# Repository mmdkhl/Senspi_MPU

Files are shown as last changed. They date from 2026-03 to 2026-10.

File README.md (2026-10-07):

# SensePi — ProTELC Science Camp

SensePi is a desktop app for measuring how a model structure vibrates. It connects over the network to a
Raspberry Pi that has **four MPU6050 motion sensors** attached. You can watch the signals live, record
them, look at their frequency content, and compare them with a computer model of the structure.

This page shows you how to get the app running on **your own computer** for the first time. It takes
about 15 minutes, and most of that is waiting for downloads.

> **At the camp, the Raspberry Pis are already set up for you.** All you need is the app on your laptop
> and the connection details (IP address, username, password) your instructor gives you. To talk to
> a Pi, your laptop must be connected to the **`MissionControl`** Wi-Fi network.

---

## Quick start

### Step 1: Install the tools (one time only)

You need two free programs:

| Program | Where to get it | Notes |
|---|---|---|
| **Python 3.12** | https://www.python.org/downloads/release/python-31210/ | On Windows, tick **"Add python.exe to PATH"** on the first installer screen. |
| **Git** | https://git-scm.com/downloads | The default options are fine. |

Use **Python 3.12**. Newer versions (3.13, 3.14) install without errors, but on Windows the *Model
Updating* tab then fails, because its OpenSees engine is only built for 3.12. If you already have a
different Python, install 3.12 next to it.

To check that both are installed, open a **new** terminal (Windows: press the Start key and type
`PowerShell`; macOS: open *Terminal*) and run:

```bash
python --version
git --version
```

The first command should print `Python 3.12.x`. On macOS/Linux, use `python3.12` in place of
`python`.

### Step 2: Download the app

The commands below download only the parts of the project the app needs, so the download stays small:

```bash
git clone --depth 1 --filter=blob:none --sparse https://github.com/mmdkhl/Senspi_MPU.git
cd Senspi_MPU
git sparse-checkout set src
```

This creates a folder called `Senspi_MPU` inside whatever folder your terminal was in (usually your
user folder). The rest of this guide runs commands **from inside that folder**.

<details>
<summary>No Git? Download a ZIP instead</summary>

Open https://github.com/mmdkhl/Senspi_MPU and click **Code → Download ZIP**. Unzip it, then open a
terminal in the unzipped folder. You get the whole project this way, which is fine but a bigger download.
</details>

### Step 3: Install the app

Create a private Python environment for the app so it doesn't interfere with anything else on your
computer, then install the app into it.

**Windows (PowerShell):**

```powershell
python -m venv .venv
.venv\Scripts\Activate.ps1
python -m pip install --upgrade pip
pip install -r requirements.txt
```

**macOS / Linux:**

```bash
python3 -m venv .venv
source .venv/bin/activate
python -m pip install --upgrade pip
pip install -r requirements.txt
```

`requirements.txt` installs **everything** — every tab works after this, including *Spectrum*,
*Model Updating* and the sound in *Sonification*. There is nothing else to add later.

When the environment is active, your prompt starts with `(.venv)`. The install downloads a few hundred MB
and can take several minutes.

> **Windows: "running scripts is disabled on this system"?** Run this once, then try
> `Activate.ps1` again:
> ```powershell
> Set-ExecutionPolicy -Scope CurrentUser RemoteSigned
> ```

### Step 4: Start the app

```bash
python main.py
```

The SensePi window opens. (On macOS/Linux use `python3` if `python` is not found.)

### Step 5: Connect to your Raspberry Pi

> **Connect your laptop to the `MissionControl` Wi-Fi network first.** The Raspberry Pis are only
> reachable on `MissionControl`, so the app can't find them from any other network. Do Steps 1–3 on a
> network with internet access, because `MissionControl` may not have any.

1. Open the **Settings** tab.
2. Under **Raspberry Pi hosts**, fill in the example entry like this:

   | Field | Value |
   |---|---|
   | **Name** | any name you like, for example `Pi-1` |
   | **Host / IP** | the Pi's IP address, from your instructor (the Pi's small screen also shows it) |
   | **User** | `verwalter` |
   | **SSH port** | `22` |
   | **Password** | from your instructor |
   | **Scripts base path** | `/home/verwalter/sensor4` |
   | **Data directory** | `/home/verwalter/logs` |
   | **Pi config path** | `/home/verwalter/sensor4/pi_config.yaml` |

   Type the paths exactly as shown. They point to the **4-sensor** scripts on the camp Pis.
3. Click **Save host config**.
4. Check that **Number of sensors** is set to **4 sensors**. This is the default.
5. In the **sensor map**, set the floor and position of each sensor to match your structure. Every other
   tab uses this map, so get it right here. Then click **Save sensors.yaml**.
6. Click **Sync Pi defaults (pi_config.yaml)** to send these settings to the Pi.

### Step 6: Measure!

1. Go to **Live Signals** and click **Start**. Tap the structure and watch the signals move.
2. Click **Stop** when you're done.
3. To keep a measurement, set the recording length and click **Smart Record**. The app checks the real
   sampling rate for a few seconds, then records for the length you chose.

---

## Starting the app again later

You only do Steps 1–3 once. After that, open a terminal and run:

**Windows:**
```powershell
cd Senspi_MPU
.venv\Scripts\Activate.ps1
python main.py
```

**macOS / Linux:**
```bash
cd Senspi_MPU
source .venv/bin/activate
python main.py
```

To get the latest version of the app (for example when your instructor announces an update), run this in
the `Senspi_MPU` folder:

```bash
git pull
```

---

## What's in the app

| Tab | What it does |
|---|---|
| **Live Signals** | Streams the four sensors live and records measurements |
| **Spectrum** | Shows which frequencies the structure vibrates at (its natural frequencies and mode shapes) |
| **Model Updating** | Tunes a computer (OpenSees) model of the structure so it matches your measurements. Its sub-tabs are Model, Additional Mass, Analysis, Calibration, **Digital Twin** (the tuned model's response beside the measurement) and **Digital Shadow** (the model run live alongside the real structure) |
| **Sonification** | Turns the vibrations into sound |
| **Settings** | Raspberry Pi connection, number of sensors, sensor positions and sampling rate |

### Where your data is saved

Everything the app produces goes into the `output/` folder inside `Senspi_MPU`:

```text
output/
  sensor_recordings/   your recorded measurements (one folder per recording)
  model/               computer-model files
  digital_twin/        Digital Shadow runs
  sonification/        audio you captured
```

---

## Troubleshooting

**`python` or `git` is "not recognized" / "command not found"**
Close the terminal and open a new one. If it still fails, reinstall Python and make sure **"Add
python.exe to PATH"** is ticked. On macOS/Linux, try `python3`.

**`No module named 'PySide6'` (or another package) when starting the app**
The environment isn't active. Run the `Activate` line from Step 3 — your prompt should show `(.venv)` —
then `python main.py` again. Run `python main.py` from inside the `Senspi_MPU` folder.

**The *Model Updating* tab says OpenSees is missing, or *Sonification* has no sound**
The dependencies didn't all install. With the environment active, run
`pip install -r requirements.txt` again and read the output for errors.

**Can't connect to the Pi**
- Is your laptop connected to the **`MissionControl`** Wi-Fi? (Laptops sometimes switch back to another
  saved network on their own.)
- Check the IP address, username and password in **Settings**.
- Ask your instructor whether the Pi is switched on. Its small screen shows its IP address.

**No signal / a sensor is missing**
- Check that **Number of sensors** is set to 4 and click **Sync Pi defaults (pi_config.yaml)** again.
- Check that the sensor cables are firmly connected, then tell your instructor.

**Plots are slow or jerky**
Lower the sample rate in **Settings**, or close other heavy programs.

---

## For instructors: preparing a Raspberry Pi

The Pi-side scripts for the 4-sensor setup (four MPU6050s on I2C buses 0 and 1, plus an OLED status
display) are in [`raspberrypi_scripts_4_sensor/`](raspberrypi_scripts_4_sensor/). Its
[`README_rpi.md`](raspberrypi_scripts_4_sensor/README_rpi.md) covers wiring, copying the scripts to the
Pi, installing dependencies (offline wheels included) and checking the sensors.

A student clone made with Step 2 doesn't include that folder. To get it, run
`git sparse-checkout add raspberrypi_scripts_4_sensor`, or clone the full repository.

Notes:
- The camp Pis use the user `verwalter`, with the 4-sensor scripts copied to `/home/verwalter/sensor4`.
  The student setup (Step 5) depends on these paths, so keep them the same on every Pi.
- `output_dir` in `pi_config.yaml` must be `/home/verwalter/logs/mpu` (inside the `verwalter` home
  directory).
- `deploy_pi.bat` / `deploy_pi.example.bat` copy the 4-sensor folder to the Pi. Set `REMOTE_DIR`
  (and the matching "Refusing to wipe" guard line) to the Pi's real folder first, for example
  `/home/verwalter/sensor4`: the script empties that folder before copying.

### Keeping credentials out of Git

The GUI saves real host details to `src/sensepi/config/hosts.local.yaml`, which Git ignores. The tracked
`hosts.yaml` / `hosts.example.yaml` contain placeholder values only. Never commit real IP addresses or
passwords.

---

## For developers

See [`docs/DEVELOPERS.md`](docs/DEVELOPERS.md) for the architecture, config files and tests.

`requirements.txt` is the complete dependency set and keeps step with `[project].dependencies` plus the
`model-updating` extra in `pyproject.toml`. OpenSees stays an extra in the package metadata (guardrail
G8) so `sensepi` can be imported as a library without it; `requirements.txt` installs it anyway, so the
app is always complete.

Installing the package itself adds the console commands:

```bash
pip install -e .          # adds sensepi-gui, sensepi-sonify, opensees-calibrate
sensepi-sonify --input path/to/data.csv --out out.wav --mode harmonic --joint 28 --r1-measurement R1 --u1-measurement U1
```

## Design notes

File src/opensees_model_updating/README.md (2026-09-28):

# opensees-model-updating

> Automated finite-element model updating for 3-D aluminum frames using OpenSeesPy and scipy.

A desktop application that builds a parametric OpenSees model of a multi-story 3-D moment frame, runs an automatic modal calibration against experimentally identified frequencies (and optionally mode shapes), then performs a Newmark transient analysis with real-time visualization — all driven by a three-tab Tkinter GUI.

---

## Table of contents

- [Background](#background)
- [How model updating works](#how-model-updating-works)
  - [The finite-element model](#the-finite-element-model)
  - [The calibration algorithm](#the-calibration-algorithm)
  - [The transient analysis](#the-transient-analysis)
- [Quick start](#quick-start)
- [Installation](#installation)
- [Running the application](#running-the-application)
- [GUI walkthrough](#gui-walkthrough)
- [Input files](#input-files)
- [Output files](#output-files)
- [Repository layout](#repository-layout)
- [Python API](#python-api)
- [Legacy reference](#legacy-reference)
- [Contributing](#contributing)

---

## Background

Structural model updating is the process of adjusting the parameters of a numerical finite-element model so that its dynamic behaviour matches measurements taken from a real structure. This repository implements a practical workflow for a scaled laboratory aluminum frame:

1. **System identification** — modal frequencies (and optionally mode shapes) are extracted from measured vibration data and stored in a JSON file.
2. **FE model construction** — OpenSeesPy builds a 3-D Euler–Bernoulli beam-column frame with rigid diaphragms, self-weight masses, and optional point masses.
3. **Automatic calibration** — a bounded nonlinear least-squares optimizer adjusts the Young's modulus scale and per-story mass scales to minimise the mismatch between numerical and experimental modal properties.
4. **Transient analysis** — the calibrated model is excited by a recorded ground-motion and the roof displacement response is animated in real time.

---

## How model updating works

### The finite-element model

The frame is a 1-bay-by-1-bay, N-story structure built entirely in OpenSeesPy:

- **Nodes** — four corner nodes and one master node per floor (plus four fixed base nodes). The master node sits at the geometric centroid of each floor.
- **Elements** — `elasticBeamColumn` elements for all columns and beams, using tabulated section properties derived from user-supplied dimensions (thickness × width for columns, height × width for beams).
- **Column orientation** — each column can be individually set to *weak-axis* or *strong-axis* bending relative to the X-direction of excitation. Internally this changes the geometric transformation vector from `(1,0,0)` to `(0,1,0)`.
- **Rigid diaphragm** — `ops.rigidDiaphragm(3, master, *corner_nodes)` constrains each floor to in-plane rigid-body motion in the horizontal plane.
- **Mass** — translational mass is lumped at the master node (self-weight) and optionally at each corner (additional point masses). The rotational mass moment of inertia for each floor is computed from its plan dimensions and total mass.
- **Gravity** — a static load case applies gravity to the corner masses, and `ops.loadConst('-time', 0.0)` resets the time origin before dynamic analysis.

Section properties are computed from standard thin-walled mechanics:

```
I = (b * h^3)/12  -  (b - 2t) * (h - 2t)^3 / 12
A = b*h  -  (b - 2t)*(h - 2t)
J ≈ 2*t*(b-t)^2*(h-t)^2 / (b + h - 2t)
```

### The calibration algorithm

The calibration is a **bounded nonlinear least-squares** problem solved by `scipy.optimize.least_squares` with the Trust-Region Reflective (`trf`) method and `soft_l1` loss (robust to outliers).

**Calibration parameters** — the optimizer searches over a vector:

```
x = [alpha_E,  alpha_m1,  alpha_m2,  ...,  alpha_mN]
```

where `alpha_E` scales Young's modulus and `alpha_mi` scales the mass of story `i`.
All scales start at `1.0` (no change) and are bounded to `[lb, ub]` (default 0.70–1.30).

**Objective function** — at each optimizer iteration the full OpenSees model is rebuilt and an eigenvalue analysis is run. The residual vector is:

```
r = [w_freq * (f_num_k - f_exp_k) / f_exp_k]   for k = 1 .. n_calib_modes
  + [w_mode * (phi_num_kj - phi_exp_kj)]        for each mode k, floor j  (optional)
```

where frequencies are in Hz and mode shapes are max-abs-normalised and sign-aligned before differencing. If the model fails during an optimizer iteration, a large penalty (1×10³) is returned to steer the solver away from that region.

**Eigenvalue solver fallback** — OpenSees uses ARPACK by default. For small models or when many modes are requested relative to the number of inertial DOFs, ARPACK can be numerically unstable. The code automatically retries with `fullGenLapack` if ARPACK fails.

**Result** — the optimizer returns the best-fit `x*` and the calibrated parameters become:

```
E_cal   = alpha_E*   * E_nominal
m_i_cal = alpha_mi*  * m_i_nominal    for each story i
```

### The transient analysis

After calibration, Rayleigh damping coefficients are computed from the first two numerical modes to target a uniform damping ratio `zeta`:

```
alpha = 2 * zeta * omega1 * omega2 / (omega1 + omega2)
beta  = 2 * zeta / (omega1 + omega2)
```

Ground motion is applied as a uniform base excitation in the X-direction via `ops.UniformExcitation`. The time integration uses the **Newmark average acceleration method** (`gamma = 0.5`, `beta = 0.25`, unconditionally stable). Floor displacement and acceleration recorders are written to `output/*.out`. During the run, a live matplotlib animation updates every 10 time steps, showing the deformed frame shape at 20× amplification alongside the roof displacement time-history. If a pre-calibration response was stored, it is overlaid in grey for direct visual comparison.

---

## Quick start

```bash
# 1. Clone the repository
git clone https://github.com/<your-org>/opensees-model-updating.git
cd opensees-model-updating

# 2. Create the conda environment
conda env create -f environment.yml
conda activate opensees

# 3. Run
python run.py
```

---

## Installation

### Requirements

| Dependency | Minimum version | Purpose |
|---|---|---|
| Python | 3.9 | Language runtime |
| openseespy | 3.4.0 | FE model + analysis |
| numpy | 1.20 | Numerical arrays |
| scipy | 1.7 | Least-squares optimizer |
| matplotlib | 3.3 | Plots + real-time animation |
| opsvis | 1.0 | Mode-shape visualisation |

### Step by step

```bash
# Using the provided environment file (recommended)
conda env create -f environment.yml
conda activate opensees

# Or manually
conda create -n opensees python=3.11
conda activate opensees
pip install openseespy numpy scipy matplotlib opsvis
```

---

## Running the application

```bash
# From the repository root, with the opensees environment active:
python run.py
```

---

## GUI walkthrough

The GUI has three tabs and two action buttons.

### Tab 1 — Basic Model

| Field | Description |
|---|---|
| Building length X / width Y | Plan dimensions in metres |
| Number of stories | Updating this field instantly rebuilds all story tables |
| Column thickness / width | Cross-section of each column (m) |
| Beam thickness / height | Cross-section of each beam (m) |
| Story height table | Per-story height (m) and self-weight floor mass (kg) |
| Columns present | Checkboxes C1–C4 per story; unchecked columns are omitted from the model |
| Column orientation | Per-story, per-column: Weak axis or Strong axis relative to X-shaking |

The 3-D sketch on the right updates live as you change the story count or column orientation.

### Tab 2 — Mass + Analysis

| Field | Description |
|---|---|
| Elastic modulus E | Young's modulus in Pa (e.g. `200e9`) |
| Poisson ratio ν | Used to derive shear modulus G |
| Additional mass table | Per-story extra masses (kg) at the floor centroid and corners C1–C4 |
| Number of modes | Total eigenvalues to extract from the FE model |
| Damping ratio ζ | Target Rayleigh damping ratio |
| Ground-motion file | Path to a plain-text acceleration record (m/s²) |
| Ground-motion dt | Sampling time step of the record (s) |
| Ground-motion scale factor | Multiplier applied to the record (e.g. `9.81` to convert g to m/s²) |
| Run transient after calibration | If unchecked, only modal analysis is performed |

### Tab 3 — Calibration

| Field | Description |
|---|---|
| Enable automatic calibration | Toggle the entire calibration step |
| Use mode shapes | Include mode-shape residuals in the objective (requires shapes in JSON) |
| Mass calibration target | Scale self-weight masses only, or self-weight + additional masses |
| Number of calibration modes | How many experimental modes to match (must be ≤ numModes and ≤ nStory) |
| Frequency / mode-shape weights | Relative weighting of the two residual components |
| E scale bounds | Lower and upper multiplier limits for Young's modulus |
| Mass scale bounds | Lower and upper multiplier limits for each story mass |
| Max optimizer evaluations | Hard cap on function evaluations; increase for tighter convergence |
| Show uncalibrated response | Overlay the pre-calibration roof response on the final animation |

### Action buttons

| Button | What it does |
|---|---|
| **Calibrate** | Runs calibration, saves all reports to `output/`, stores calibrated state in memory |
| **Run Analysis** | Uses the stored calibrated parameters (or current inputs if not yet calibrated) to run modal + transient analysis |
| Cancel | Exits the application |

> **Tip:** always click **Calibrate** before **Run Analysis**. If you change any input after calibrating, the application warns you and lets you choose whether to proceed uncalibrated or go back and recalibrate.

---

## Input files

### `input/experimental_modal_data.json`

The primary integration point. See [docs/pipeline.md](docs/pipeline.md) for the full data-flow reference and how to connect an automated sensor pipeline.

```json
{
  "frequencies_hz": [2.1, 5.8, 11.3],
  "mode_shapes_ux": [
    [0.33, 0.67, 1.00],
    [0.87, 0.50, -1.00],
    [1.00, -0.78, 0.34]
  ]
}
```

| Field | Required | Description |
|---|---|---|
| `frequencies_hz` | **Yes** | Identified natural frequencies in Hz, ordered lowest to highest |
| `mode_shapes_ux` | No | UX mode shape at each floor (bottom to top), one list per mode. Values need not be normalised. |

Rules:
- The list must contain at least `nCalibModes` entries.
- If `mode_shapes_ux` is provided, each inner list must have exactly `nStory` values.
- If omitted, calibration runs on frequencies only.

### `input/sine_*Hz_accel.txt`

Plain-text ground-motion records, one acceleration value per line (m/s²), sampled uniformly at `dtGM` seconds. Point the **Ground-motion file** field to whichever record you want to use.

---

## Output files

All files are written to `output/` relative to the working directory. The folder is gitignored (only `.gitkeep` is committed).

| File | Description |
|---|---|
| `original_inputs.json` | Full parameter dict before calibration |
| `calibrated_inputs.json` | Full parameter dict after calibration |
| `calibrated_inputs_used_for_run.json` | Exact parameters sent to transient analysis |
| `current_run_inputs.json` | Parameters for the most recent run |
| `experimental_modal_data_loaded.json` | Experimental data as parsed and validated |
| `modal_comparison_report.json` | Structured before/after comparison (frequencies, percent errors) |
| `modal_comparison_report.txt` | Human-readable version of the same report |
| `calibration_summary.png` | 4-panel figure: frequency bar chart, mass bar chart, mode shapes, text summary |
| `original_transient_response_overlay.npz` | Pre-calibration roof time-history for overlay plot |
| `original_periods.out` | OpenSees period file, original model |
| `calibrated_periods.out` | OpenSees period file, calibrated model |
| `*_mode_shapes_normalized.out` | Max-abs-normalised UX mode shapes |
| `*time_floor_disp_X.out` | Floor node displacement recorder |
| `*time_floor_accel_X.out` | Floor node acceleration recorder |
| `*time_roof_disp_X.out` | Roof master-node displacement recorder |
| `*time_roof_accel_X.out` | Roof master-node acceleration recorder |

---

## Repository layout

```
opensees-model-updating/
├── docs/
│   ├── pipeline.md                  # Data-flow reference + automation guide
│   ├── developer_guide.md           # Architecture, call graph, extension guide
│   └── legacy_monolith.py           # Original single-file script (reference only)
├── input/                           # Runtime input data (committed)
│   ├── experimental_modal_data.json
│   └── sine_*Hz_accel.txt
├── output/                          # Generated at run time (gitignored)
│   └── .gitkeep
├── src/                             # The Python package (opensees_model_updating)
│   ├── __init__.py
│   ├── __main__.py
│   ├── analysis/
│   │   ├── gravity.py           — static gravity + loadConst reset
│   │   ├── modal.py             — eigenvalue extraction, ARPACK fallback, plots
│   │   └── transient.py         — Rayleigh damping, Newmark integration, animation
│   ├── calibration/
│   │   └── calibrator.py        — TRF optimizer, residual function, bounds
│   ├── cli/
│   │   └── main.py              — post-GUI analysis orchestration
│   ├── domain/
│   │   └── enums.py             — ColumnOrientation, AnalysisType, MassCalibrationScope
│   ├── gui/
│   │   ├── main_window.py       — 3-tab Tkinter GUI, Calibrate + Run buttons
│   │   └── widgets/
│   │       └── canvas_widget.py — plan-view legend, 3-D column sketch
│   ├── io/
│   │   └── loaders.py           — JSON/text I/O, experimental data validation
│   ├── model/
│   │   └── builder.py           — nodes, elements, rigid diaphragm, mass
│   ├── reporting/
│   │   └── calibration_report.py — report dicts, text formatting, summary figure
│   ├── utils/
│   │   ├── formatters.py        — r3(), sci3(), deep_round(), layout text helpers
│   │   └── math_utils.py        — mode normalisation, sign alignment, percent error
│   └── visualization/
│       └── __init__.py          — re-exports from analysis modules
├── .gitattributes
├── .gitignore
├── environment.yml
├── pyproject.toml
├── README.md
└── run.py                           — one-line launcher
```

---

## Python API

The package can be used without the GUI for automated pipelines:

```python
import json
import pathlib
from opensees_model_updating.calibration.calibrator import (
    prepare_experimental_modal_data,
    run_calibration,
)
from opensees_model_updating.analysis.modal import extract_modal_results, export_modal_files
from opensees_model_updating.reporting.calibration_report import (
    make_modal_comparison_report,
    save_calibration_summary_figure,
)

# Write experimental data (replace with your sensor pipeline output)
pathlib.Path("input/experimental_modal_data.json").write_text(
    json.dumps({
        "frequencies_hz": [2.1, 5.8],
        "mode_shapes_ux": [[0.5, 1.0], [1.0, -0.6]],
    })
)

# Define model parameters (same keys that the GUI collects)
params = {
    "nStory": 2,
    "Lx": 0.245, "Ly": 0.23,
    "story_heights": [0.24, 0.24],
    "floor_masses": [0.27, 0.27],
    "t_column": 0.001, "b_column": 0.006,
    "b_beam": 0.001,   "h_beam": 0.008,
    "E": 200e9, "nu": 0.33,
    "numModes": 2, "nCalibModes": 2,
    "zeta": 0.005, "gmFactor": 9.81,
    "gmFile": "input/sine_1Hz_accel.txt", "dtGM": 0.01,
    "enable_calibration": True, "use_mode_shapes": False,
    "mass_calibration_scope": "self_weight_only",
    "freq_tol_percent": 5.0, "w_freq": 1.0, "w_mode": 0.35,
    "E_scale_lb": 0.70, "E_scale_ub": 1.30,
    "m_scale_lb": 0.70, "m_scale_ub": 1.30,
    "max_nfev": 200, "show_info": False,
    "story_column_layout": {1: [1,2,3,4], 2: [1,2,3,4]},
    "column_orientation_layout": {
        1: {1: "weak", 2: "weak", 3: "weak", 4: "weak"},
        2: {1: "weak", 2: "weak", 3: "weak", 4: "weak"},
    },
    "additional_masses": {1: [0,0,0,0,0], 2: [0,0,0,0,0]},
}

exp_data     = prepare_experimental_modal_data(params)
modal_before = extract_modal_results(params)
calib_result, calibrated_params = run_calibration(params, exp_data)
modal_after  = extract_modal_results(calibrated_params)

export_modal_files(modal_before, "original")
export_modal_files(modal_after,  "calibrated")

report = make_modal_comparison_report(
    exp_data, modal_before, modal_after, params, calibrated_params, calib_result
)
save_calibration_summary_figure(
    exp_data, modal_before, modal_after, params, calibrated_params,
    save_path="output/calibration_summary.png",
)
print("Calibrated frequencies (Hz):", modal_after["freqs"])
```

See [docs/pipeline.md](docs/pipeline.md) for the complete integration reference including how to feed live sensor data.

---

## Legacy reference

[docs/legacy_monolith.py](docs/legacy_monolith.py) is the original single-file script (`DigitalTwin_V8.py`) from which this package was refactored. It is kept for historical reference only — do not run or import it. The developer guide contains a [function-by-function mapping](docs/developer_guide.md#legacy-reference) from the old script to the current package modules.

---

## Contributing

1. Fork the repository and create a feature branch.
2. Follow the existing code style — `black` for formatting, `ruff` for linting.
3. Add or update tests under `src/tests/`.
4. Open a pull request with a clear description of the change.

```bash
# Format and lint before committing
black src/
ruff check src/
pytest src/tests/
```

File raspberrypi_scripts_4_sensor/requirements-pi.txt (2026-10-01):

# Python packages the 4-sensor Pi scripts import (installed by install_pi_deps.sh).
#   smbus2  - I2C access to the MPU6050s (mpu6050_multi_logger.py)
#   PyYAML  - reads pi_config.yaml (pi_logger_common.py, sensepi.config)
# The OLED display's packages are in requirements-oled.txt.
smbus2
PyYAML

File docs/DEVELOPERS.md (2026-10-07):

# SensePi Developer Notes

This document is for developers who want to modify SensePi or understand how it works internally.

---

## 1) Quick dev setup (PC)

From the repo root:

```bash
python -m venv .venv
# Windows:
.venv\Scripts\activate
# Linux/macOS:
# source .venv/bin/activate

python -m pip install --upgrade pip
pip install -e .
```

Run the GUI:

```bash
python -m sensepi.gui.application
# or
sensepi-gui
```

Run unit tests:

```bash
python -m unittest discover -s tests
```

---

## 2) Repository layout (what lives where)

- `src/sensepi/gui/`  
  Qt application + the six tabs, `MainWindow`, and `RecorderController`

- `src/sensepi/remote/`  
  SSH + remote process control + log sync

- `raspberrypi_scripts_4_sensor/`  
  The scripts copied to the Raspberry Pi (e.g. `mpu6050_multi_logger.py`) for the
  current 4-sensor + OLED rig. `raspberrypi_scripts/` is the older 3-sensor
  version; its logger only accepts sensors 1–3.

- `src/sensepi/config/`  
  YAML + dataclasses for hosts/sensors/sampling and shared path conventions

- `src/sensepi/analysis/`  
  Pure NumPy/SciPy, no Qt: modal identification (`modal.py`), the sensor-map
  adapter (`sensor_layout.py`), base-referenced identification
  (`transmissibility.py`) and torsion indicators (`torsion.py`)

- `src/sensepi/digital_twin/`, `src/sensepi/sonification/`  
  The engines behind those two tabs, also Qt-free so they stay testable

- `src/opensees_model_updating/`  
  The OpenSees calibration package. Also runs standalone — see `paths.py` for how
  its output location is resolved without assuming a working directory

- `docs/`  
  `DEVELOPERS.md` (this file), `gui_pipeline_diagram.mmd`, the user manual, and
  `hardware/` — enclosure and bracket design source (Fusion `.f3d`, PCB `.dxf`,
  printable `.stl`, plus the `trimesh` script that generates the OLED bracket).
  Both the manual and the hardware files predate the current software and are
  kept for reference, not as a description of it.

- `output/` and `logs/`  
  Local runtime folders (created automatically; git-ignored). Everything the
  application *produces* lives under one root:

  ```
  output/
    sensor_recordings/<host>/mpu/<stamp>[_<name>]/   one folder per Smart Record
                                                     (main CSVs + audit_<stamp>/ six-channel copy)
    model/                          the default model workspace: input/ and output/
                                    (OpenSees recorders and calibration files)
    digital_twin/<stamp>/           experiment runs
    sonification/                   audio captures
  logs/                             diagnostics — deliberately separate
  ```

  Smart Record writes the samples **as received** (timestamps, decimation) plus an
  audit of rate, gaps and clock drift; alignment onto a common grid happens on the
  read side, in `dataio.modal_session_loader.align_per_sensor_series`, every time a
  session is loaded.

  Resolve these through `AppPaths` (`src/sensepi/config/app_config.py`), never by
  building a relative path. `SENSEPI_OUTPUT_ROOT` moves the whole tree,
  `SENSEPI_DATA_ROOT` moves the recordings folder alone, `SENSEPI_LOG_DIR` the logs.

---

## 3) Config files

### Desktop-side
- `src/sensepi/config/hosts.yaml`  
  List of Pis (host, user, password, paths)

- `src/sensepi/config/sensors.yaml`  
  Sensor defaults + sampling defaults  
  Tracked template. Per-machine state (the sensor placement map, the sensor count)
  is written to the gitignored `sensors.local.yaml`, which takes precedence when
  present — the same pattern as `hosts.local.yaml`.

### Pi-side
- `pi_config.yaml` (uploaded to each Pi)  
  Built from the desktop defaults and uploaded to `HostConfig.pi_config_path`

The GUI treats the desktop config as the source of truth.

---

## 4) Runtime architecture (end-to-end)

### Tabs in the current GUI
The main window builds these tabs:
- **Live Signals** (`src/sensepi/gui/tabs/tab_signals.py`)
- **Spectrum / FFT** (`src/sensepi/gui/tabs/tab_fft.py`)
- **Model Updating** (`src/sensepi/gui/tabs/tab_model_updating.py`) — sub-tabs
  Model, Additional Mass, Analysis, Calibration, **Digital Twin** (the output
  views: `_output_tab`) and **Digital Shadow**
- **Sonification** (`src/sensepi/gui/tabs/tab_sonification.py`) — a container with
  one sub-tab per model
- **Settings** (`src/sensepi/gui/tabs/tab_settings.py`)

Open review: [`model_updating_twin_shadow_review.md`](model_updating_twin_shadow_review.md)
records eight findings on the Model Updating tab — one of them a bug (the shadow's
own Calibrate ignores the selected calibration method) — with recommendations and
acceptance criteria. Read it before changing that tab.

**Naming, and the one crossover to know about.** The tab the UI calls **Digital
Shadow** is `tab_digital_twin.py`, backed by the `sensepi.digital_twin` package
and writing to `output/digital_twin/`; it is built by `MainWindow` (still
`MainWindow.digital_twin_tab`) and handed to Model Updating via
`host_digital_shadow()`, which keeps the dependency one-directional. The sub-tab
the UI calls **Digital Twin** is Model Updating's `_output_tab`. The internal
names were deliberately left alone when the labels changed: renaming the package
or the results folder would move users' saved experiment data.

### Sensor placement: defined once, in Settings
Where each sensor sits — its floor and its plan cell on a 3x3 grid — is set **only**
in Settings (`gui/widgets/sensor_map.py`) and fanned out by `MainWindow` to every
tab that needs it, through `apply_sensor_map()`.

**Do not add a sensor, floor or storey picker to any other tab.** Four of them used
to exist, they could disagree about the same rig, and they were removed. If a tab
needs to know where a sensor is, it takes the map and converts it with
`analysis/sensor_layout.py`, which answers the questions that actually matter:
which sensors are structural responses, which one is the shaker (floor 0, an
*input*, excluded from output-only identification), which channel the excitation
axis implies, how many modes the sensor count can support, and where a
differenceable pair exists for torsion.

### The “controller” layer
The GUI does not run SSH logic directly from the plotting tabs. Instead:
- `src/sensepi/gui/recorder_controller.py` owns start/stop, ingest, and shared buffers.
- Tabs talk to the controller via Qt signals/slots.

### Data flow (live streaming)
1. **User clicks Start** in the Live Signals tab.
2. `MainWindow` forwards this to `RecorderController.start_live_stream(...)`.
3. `RecorderController` creates a `PiRecorder` (SSH wrapper) and starts the Pi process.
4. The remote script (`mpu6050_multi_logger.py`) streams **one JSON object per line** on stdout.
5. `SensorIngestWorker` runs in a background thread, reads stdout, parses lines into `MpuSample`,
   and pushes samples into a shared `StreamingDataBuffer`.
6. `SignalsTab` and `FftTab` pull from that buffer on timers and update plots.

Key points:
- SSH / parsing / IO must stay off the Qt GUI thread.
- Plot refresh rates are independent of device sampling rate.

---

## 5) Raspberry Pi logger (what the GUI starts)

The default sensor is the MPU6050 logger:

- `raspberrypi_scripts_4_sensor/mpu6050_multi_logger.py`

The desktop starts it over SSH roughly like:

```text
python3 <base_path>/mpu6050_multi_logger.py --config <pi_config.yaml> ... --stream-stdout
```

(See `src/sensepi/remote/pi_recorder.py`.)

### Pi deployment helper
`deploy_pi.bat` copies:
- `raspberrypi_scripts_4_sensor/*` → `<REMOTE_DIR>/` (default `/home/pi/sensor4`)
- `src/sensepi/config/*.py` + `src/sensepi/__init__.py` → `<REMOTE_DIR>/sensepi/`
  (the Python modules only, so `hosts.local.yaml` and its passwords stay on the PC)

This “mini sensepi package” on the Pi exists because the Pi scripts import shared helpers
like `sensepi.config.log_paths`.

---

## 6) Log conventions + syncing

Shared log/file naming rules live in:

- `src/sensepi/config/log_paths.py`

Syncing logs from a Pi to the PC is handled by:

- `src/sensepi/remote/log_sync.py`
- `src/sensepi/remote/log_sync_worker.py`

The GUI uses the host’s `data_dir` and the sensor prefix (e.g. `mpu`) to decide what to download.

---

## 7) Where to make common changes

### A) Add / change UI controls
- Add widgets in the relevant `tab_*.py`
- Wire actions into `RecorderController` (preferred) instead of doing SSH inside tabs
- Cross-tab wiring belongs in `MainWindow._wire_signals()` — that is the only place
  tabs are connected to each other. Do not reach into another tab's private members;
  add a public method instead (`ModelUpdatingTab.model_definition_snapshot()` is the
  worked example of replacing three such reach-ins with one documented seam).

### B) Add a new plot based on the live stream
- Subscribe to the shared buffer (or expose a signal from the controller)
- Keep plotting updates timer-driven (don’t redraw per-sample)

### C) Add a new sensor type
You typically need:
1. A Pi-side logger script under `raspberrypi_scripts_4_sensor/`
2. A desktop-side parser under `src/sensepi/sensors/`
3. A config entry in `sensors.yaml` + a `PiLoggerConfig` update
4. A way for `PiRecorder` / `RecorderController` to select the correct script + prefix

---

## 8) Tips for performance and stability

- Keep all SSH + file sync in worker threads.
- **Never call `os.chdir()`.** It is process-global: it moves the working directory
  for every thread, not the caller. This application runs SSH ingest, an audio
  worker and a model worker at once, so a relative path in any of them can resolve
  somewhere else for the duration. Pass an explicit directory instead. A test fails
  if `os.chdir` reappears under `src/sensepi`.
- Avoid building new Matplotlib objects every frame; update existing lines/curves.
- Use bounded buffers (ring buffers) for live views.
- Be conservative with default sampling/plot rates so slower PCs stay responsive.

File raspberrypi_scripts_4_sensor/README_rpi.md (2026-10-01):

# SensePi Raspberry Pi scripts — 4-sensor + OLED setup

This folder is the development copy of the Pi-side scripts, extended from the
working 3-sensor deployment (`raspberrypi_scripts/`) to support a 4th
MPU6050 sensor and an I2C OLED status display. The original 3-sensor folder
is untouched; this one is safe to test independently.

## Hardware this matches

- Sensor 1: bus 1, address 0x68 (AD0 floating)
- Sensor 2: bus 1, address 0x69 (AD0 → 3.3V)
- Sensor 3: bus 0, address 0x68 (AD0 floating)
- Sensor 4: bus 0, address 0x69 (AD0 → 3.3V)
- OLED: bus 1, address 0x3C (SSD1306/SSD1315, 0.96", 128x64)

## Files

- `mpu6050_multi_logger.py` — multi-sensor MPU6050 logger, now mapping
  sensors 1–4 by default. Also writes a small status heartbeat file
  (`/tmp/sensepi_status.json`) while running, for the OLED display to read.
- `oled_status.py` — standalone script that renders IP address, publishing
  state, and sampling rate on the OLED. Runs as its own process, independent
  of the logger, by design — a crash in either one can't take down the other.
- `pi_logger_common.py` — shared helpers and configuration loading.
- `pi_config.yaml` — configuration file for rates, channels, paths, and the
  enabled sensor list (now `1, 2, 3, 4`).
- `install_pi_deps.sh` — installs Python dependencies from the two files
  below, both read from this folder.
- `requirements-pi.txt` — what the logger imports: `smbus2` and `PyYAML`.
- `requirements-oled.txt` — the OLED display's `luma.oled` + `pillow`.
- `run_all_sensors.sh` — launches the OLED display in the background, then
  the logger in the foreground; stopping the logger (Ctrl-C or a stop
  signal) also stops the OLED script.

## Setup

Replace `<user>@<host>` below with your actual Pi login (e.g. `verwalter@192.168.0.111`)
and `<target_dir>` with wherever you want this folder to live on the Pi (e.g. `~/sensor4`,
as a sibling of your existing 3-sensor folder — do not reuse the same folder name).

On your workstation:

```bash
scp -r raspberrypi_scripts_4_sensor <user>@<host>:<target_dir>
ssh <user>@<host> "chmod +x <target_dir>/run_all_sensors.sh <target_dir>/install_pi_deps.sh"
```

This folder does not ship its own `sensepi/` package — `mpu6050_multi_logger.py` imports
`sensepi.config.log_paths`, and Python auto-adds a script's own directory to its import
path, so `sensepi/` just needs to sit next to the script. If your existing 3-sensor folder
already has a working `sensepi/` copy (check with `find <existing_folder> -maxdepth 1 -name
sensepi`), reuse it instead of transferring a fresh one:

```bash
ssh <user>@<host> "cp -r <existing_3sensor_dir>/sensepi <target_dir>/sensepi"
```

Before installing, confirm `output_dir` in `pi_config.yaml` matches your actual home
directory on the Pi (it defaults to `/home/pi/logs/mpu`, which will fail with a permission
error if your Pi user isn't literally named `pi` — check with `ssh <user>@<host> whoami`).

```bash
ssh <user>@<host> "bash <target_dir>/install_pi_deps.sh"
```

If this fails with `error: externally-managed-environment`, the script's `pip3 install`
calls need `--break-system-packages` added (safe here since it's a `--user` install, not a
system-wide one) — this is already fixed in this folder's `install_pi_deps.sh` as of the
last update.

Verify wiring before running anything:

```bash
ssh <user>@<host> "cd <target_dir> && python3 mpu6050_multi_logger.py --list"
```

You should see `WHO_AM_I=0x68` on both `0x68` and `0x69`, on both bus 0 and bus 1 — not
just an address match, the actual register read matters (a stuck/shorted bus can make every
address falsely appear present). Confirm the OLED separately:

```bash
ssh <user>@<host> "sudo /usr/sbin/i2cdetect -y 1"
```

(look for `3c`; use the full `/usr/sbin/i2cdetect` path if you get `command not found` —
`/usr/sbin` often isn't on `PATH` for non-interactive SSH sessions even when the package is
installed). `--list` above only checks 0x68/0x69, so it won't catch OLED wiring issues.

Then run everything (logger + OLED display together):

```bash
ssh <user>@<host> "cd <target_dir> && ./run_all_sensors.sh"
```

Or run the OLED display on its own, e.g. while testing the logger separately:

```bash
python3 oled_status.py --interval 1.0
```

## Notes

- INT, XDA, and XCL are unused on every sensor — nothing in this codebase
  reads them, so they can stay unconnected.
- This folder only changes the Pi-side scripts. The desktop GUI
  (`src/sensepi/gui/...`) still assumes 3 sensors and hasn't been touched;
  that's a separate follow-up once this 4-sensor acquisition path is
  validated on the Pi.

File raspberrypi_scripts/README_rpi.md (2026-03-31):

# SensePi Raspberry Pi scripts

This folder contains the lightweight logger scripts that should be copied to a Raspberry Pi. They record MPU6050 sensor data locally on the device and can optionally stream lines over stdout for live viewing.

## Files

- `mpu6050_multi_logger.py` – multi-sensor MPU6050 logger.
- `pi_logger_common.py` – shared helpers and configuration loading.
- `pi_config.yaml` – example configuration file for rates, channels, and paths.
- `install_pi_deps.sh` – installs Python dependencies on the Pi.
- `run_all_sensors.sh` – simple launcher for the MPU6050 logger.

## Setup

On your workstation:

```bash
scp -r raspberrypi_scripts pi@<host>:/home/pi/
ssh pi@<host> "bash /home/pi/raspberrypi_scripts/install_pi_deps.sh"
```

Then edit pi_config.yaml on the Pi to match your logging directory and sensor layout, and run:

```bash
ssh pi@<host> "cd /home/pi/raspberrypi_scripts && ./run_all_sensors.sh"
```

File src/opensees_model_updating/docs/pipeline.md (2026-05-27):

# Data Pipeline Reference

This document describes every file that flows **into** and **out of** the application,
where each is consumed in code, and how to connect an external data source in the future.

---

## Overview

```
[Experiment / Sensor system]
         │
         ▼
  input/experimental_modal_data.json   ◄── PRIMARY INTEGRATION POINT
         │
         ▼
  opensees_model_updating/io/loaders.py  (src/io/loaders.py)
  load_experimental_modal_data()
         │
         ▼
  opensees_model_updating/calibration/calibrator.py  (src/calibration/calibrator.py)
  prepare_experimental_modal_data()
  modal_residuals()  ◄── optimizer objective function
  run_calibration()
         │
         ▼
  output/calibrated_inputs.json
  output/modal_comparison_report.json
  output/calibration_summary.png
         │
         ▼
  [Transient analysis with calibrated model]
         │
         ▼
  output/*.out  (node recorders)
  output/original_transient_response_overlay.npz
```

---

## Input files

### 1. `input/experimental_modal_data.json` — **main integration point**

**What it contains:**

```json
{
  "frequencies_hz": [2.1, 5.8, 11.3],
  "mode_shapes_ux": [
    [0.33, 0.67, 1.00],
    [0.87, 0.50, -1.00],
    [1.00, -0.78, 0.34]
  ]
}
```

| Field | Type | Required | Description |
|---|---|---|---|
| `frequencies_hz` | `list[float]` | **Yes** | Identified natural frequencies in Hz, ordered from lowest to highest |
| `mode_shapes_ux` | `list[list[float]]` | No | UX mode shape values at each floor level, one list per mode; roof value should be largest magnitude |

**Rules:**
- `frequencies_hz` must have at least as many entries as `nCalibModes` (set in the GUI).
- `mode_shapes_ux[i]` must have exactly `nStory` values (one per floor). If omitted, the calibrator uses frequencies only.
- Values are not required to be normalized — the code normalizes internally using max-abs normalization.

**Where it is read:**

```
src/io/loaders.py
  → EXPERIMENTAL_MODAL_JSON = "input/experimental_modal_data.json"   (line 12)
  → load_experimental_modal_data(json_path, nStory, require_mode_shapes)
```

```
src/calibration/calibrator.py
  → prepare_experimental_modal_data(params)   (calls load_experimental_modal_data)
```

**How to connect an automated pipeline:**

Replace or overwrite `input/experimental_modal_data.json` before calling the calibrator.
If running headlessly (no GUI), call the Python API directly:

```python
from opensees_model_updating.calibration.calibrator import (
    prepare_experimental_modal_data,
    run_calibration,
)
from opensees_model_updating.analysis.modal import extract_modal_results

# Write your sensor data here
import json, pathlib
pathlib.Path("input/experimental_modal_data.json").write_text(
    json.dumps({"frequencies_hz": [2.1, 5.8], "mode_shapes_ux": [[0.5, 1.0], [1.0, -0.6]]})
)

# Then run calibration
params = { ... }   # model parameters dict (same keys as GUI)
exp_data = prepare_experimental_modal_data(params)
calib_result, calibrated_params = run_calibration(params, exp_data)
```

---

### 2. `input/sine_*Hz_accel.txt` — ground-motion records

Plain-text, one acceleration value per line (m/s²), sampled at `dtGM` seconds.

Selected in the GUI **Ground-motion file** field.  
Read in:

```
src/analysis/transient.py
  → setup_dynamic_excitation(params)
  → ops.timeSeries('Path', ..., '-filePath', params["gmFile"])
```

To connect a real accelerometer feed, write the record as a plain-text file and point the GUI field (or `params["gmFile"]`) to it.

---

## Output files

All outputs land in `output/` relative to the working directory.

| File | Produced by | Description |
|---|---|---|
| `original_inputs.json` | `gui/main_window.py` → `calibrate_clicked()` | Raw GUI parameters before calibration |
| `calibrated_inputs.json` | same | Parameters after calibration |
| `calibrated_inputs_used_for_run.json` | `cli/main.py` | Exact params sent to transient analysis |
| `current_run_inputs.json` | `cli/main.py` | Params for the current run |
| `experimental_modal_data_loaded.json` | `gui/main_window.py` → `calibrate_clicked()` | Experimental data as parsed |
| `modal_comparison_report.json` | `reporting/calibration_report.py` | Structured before/after comparison |
| `modal_comparison_report.txt` | same | Human-readable version |
| `calibration_summary.png` | same | 4-panel figure (frequencies, masses, mode shapes, text) |
| `original_transient_response_overlay.npz` | `analysis/transient.py` | Roof time-history before calibration (for overlay plot) |
| `original_periods.out` | `analysis/modal.py` | OpenSees period file, pre-calibration |
| `calibrated_periods.out` | same | Post-calibration |
| `*_mode_shapes_normalized.out` | same | Normalized UX mode shapes |
| `*time_floor_disp_X.out` | `analysis/transient.py` | Floor displacement recorder |
| `*time_floor_accel_X.out` | same | Floor acceleration recorder |
| `*time_roof_disp_X.out` | same | Roof displacement recorder |
| `*time_roof_accel_X.out` | same | Roof acceleration recorder |

---

## Future integration checklist

To fully automate this pipeline without the GUI:

- [ ] Write `input/experimental_modal_data.json` from your sensor/identification software
- [ ] Write the ground-motion record to `input/<name>.txt`
- [ ] Build a `params` dict (all keys listed in `src/gui/main_window.py → collect_gui_inputs()`)
- [ ] Call `prepare_experimental_modal_data` → `run_calibration` → `extract_modal_results`
- [ ] Read outputs from `output/` or consume the return values directly in Python

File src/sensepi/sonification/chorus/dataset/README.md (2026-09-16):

# Bioacoustic dataset — archive and tooling

Lives with the sonification code it belongs to, not in a separate top-level
folder. Everything needed to reproduce the species material used by the
**Bioacoustic Chorus** model.

The raw audio downloads (~1.1 GB) are **not** required and were deliberately
deleted on 2026-07-30. This folder is what replaced them. Regeneration of the
shipped catalog was verified byte-identical *after* that deletion, with no
`data/` folders present at all.

```
chorus/
├── data/        runtime, shipped, read by catalog.py       (12 MB)
└── dataset/     this folder: archive + build tooling        (30 MB)
```

## What the app actually needs at runtime

Only two files, and they are committed inside the package:

```
src/sensepi/sonification/chorus/data/
├── species_catalog.json     121 species, measured, typed (10 animal types)
├── grain_banks.npz          6,157 real call units, float16   (12 MB)
└── ATTRIBUTION.md            licences + observers of every shipped species
```

Nothing under `data/` is read at runtime. `catalog.py` resolves its data
directory as `Path(__file__).with_name("data")`, i.e. inside the installed
package. Verified by hiding `data/` entirely and running the suite.

## What is in this folder

| File | Purpose | Re-obtainable? |
|---|---|---|
| `download_manifest.json` | **The re-download recipe.** 855 recordings (473 insects/frogs from July + 382 for the 2026-09 types): species, licence, observer, observation URL, direct audio URL | No — iNaturalist result ordering changes over time, so a fresh query returns a *different* set. This pins the exact one used. |
| `measured_grains_full.npz` | Extracted call units for all **264** usable species (30 MB, float16) — **this is what makes the raw audio disposable** | Yes, but only by re-downloading ~180 MB and re-extracting |
| `measured_catalog_full.json` | Measurements for all 264 species (carrier, chirp rate, pulse rate, unit length, SNR) | Derived from the above |
| `ATTRIBUTION_full.md` | Attribution for all 855 downloads | No, without the manifest |
| `fetch_dataset.py` | First download pass (insects + frogs) | — |
| `fetch_more.py` | Expansion pass, merges into the manifest | — |
| `fetch_types.py` | **2026-09-15:** woodpeckers, owls, bats, doves, squirrels, true grasshoppers | — |
| `build_catalog.py` | Measures recordings and cuts call units (taxon-limited carrier windows per group) | — |
| `merge_measured.py` | Folds a fresh build into the full extraction beside this script, so the raw audio stays disposable | — |
| `prune_catalog.py` | Selects the shipped subset **per animal type** and writes the package data | — |

## The key insight (why the raw audio was disposable)

The raw MP3/M4A files were only ever needed to **extract grains from**. Once
`build_catalog.py` has measured each recording and cut its call units, the source
audio contributes nothing further. That extraction is
`measured_grains_full.npz` — 30 MB standing in for ~1.2 GB of audio plus
WAV cache, covering 264 species rather than the 121 that ship.

A further 950 MB of the deleted folder was just a decompressed WAV cache that
`build_catalog.py` regenerates from the originals in seconds.

## Regenerating the shipped catalog (no download needed)

`prune_catalog.py` defaults to reading the preserved full extraction beside it:

```bash
python src/sensepi/sonification/chorus/dataset/prune_catalog.py
```

This rewrites `src/sensepi/sonification/chorus/data/`. Verified byte-identical to
the committed files. Change `TARGET`, `C_LO` or `C_HI` at the top to ship a
different subset — for example more species for finer damage resolution, or a
narrower carrier range for small speakers.

### Animal types (since 2026-09-15)

The user assigns one **animal type** to each mode and to each structural case
(resonance, torsion, impact, drift, ambient) in the tab; inside a type the
structure's frequency picks the species. Types and their taxonomic groups are
declared once, in `chorus/types.py` (`TYPES`): frogs, crickets (Gryllidae +
Oecanthinae), katydids, cicadas, woodpeckers, owls, bats, doves, squirrels,
grasshoppers. `prune_catalog.py` writes the `type` field into every catalog
entry and fills a per-type quota.

### Choosing how many species

The count is a resolution decision, not a taste one. Each type maps the whole
0–20 Hz building range onto **its own** catalogued carrier span (an owl register
is 0.3–1.5 kHz, a katydid register 5–15 kHz), so every type needs enough species,
evenly spread over that span, that a *meaningful* stiffness loss (~10–15 %)
moves the pick to a neighbour while identification noise does not. 12–15
species over ~2 octaves gives ~0.15–0.2-octave spacing, which is the quota.

Selection is by **even carrier coverage within the type** (best SNR per
log-spaced bin), not best SNR overall — the latter clumps wherever recordings
happen to be good and leaves octave-wide gaps.

**Bats:** iNaturalist transcodes every upload to MP3/M4A (≤ 48 kHz), so nothing
ultrasonic survives. The bat recordings are heterodyne / time-expansion detector
output or audible social calls, and are measured like any other audible
recording in a 1–16 kHz window. No pitch division is applied.

## Re-downloading the raw audio (only if you must)

Needed only to add species beyond the 139 already extracted, or to re-cut units
with different parameters (longer grains, different onset threshold).

```bash
python src/sensepi/sonification/chorus/dataset/fetch_dataset.py     # writes data/raw/bioacoustics/
python src/sensepi/sonification/chorus/dataset/fetch_more.py        # expansion pass
python src/sensepi/sonification/chorus/dataset/fetch_types.py       # the 2026-09 animal types
python src/sensepi/sonification/chorus/dataset/build_catalog.py     # measure + cut units
python src/sensepi/sonification/chorus/dataset/merge_measured.py    # fold into the full extraction
python src/sensepi/sonification/chorus/dataset/prune_catalog.py     # select the shipped subset
```

To add a new animal type: add it to `TYPES` in `chorus/types.py`, add its
iNaturalist taxon id to `fetch_types.GROUPS` and its carrier window to
`build_catalog.CARRIER_BAND`, then run the four steps above. The tab's menus
are built from the types that actually have species in the shipped catalog.

`fetch_*.py` write to `data/raw/bioacoustics/` (gitignored) and expect ~180 MB of
originals plus a ~950 MB WAV cache, which can be deleted afterwards:

```bash
rm -rf data/raw/bioacoustics/_wav
```

The manifest URLs were spot-checked live and resolve, but iNaturalist may
eventually retire an asset. `download_manifest.json` records the observation URL
alongside each audio URL, so an individual recording can be located by hand.

## Licensing — non-negotiable

All material is Creative Commons, filtered at download time to CC0 / CC-BY /
CC-BY-SA / CC-BY-NC / CC-BY-NC-SA. Most is **CC-BY-NC: non-commercial use only**,
which is more restrictive than the rest of this repository.

`ATTRIBUTION.md` ships inside the package and **must travel with the grain
bank** wherever it is redistributed. `ATTRIBUTION_full.md` here covers all 473
downloads. About a dozen manifest rows read "see iNaturalist" for the observer —
those lost their metadata when an early script overwrote the manifest; re-fetch
them from the observation URL before any redistribution.

## Three measurement traps (do not reintroduce)

`build_catalog.py` had all of these and they are worth remembering:

1. **The carrier search must be taxon-limited.** Unrestricted, wind and handling
   rumble win the spectral peak and a cicada gets recorded as a 183 Hz species.
   Insects are searched above 1.5 kHz, frogs above 250 Hz.
2. **The two timescales must be measured separately.** The slow envelope
   modulation peak is the *chirp* rate; the fast one is the *tooth-strike* rate.
   Conflating them makes every species fire one lonely tick per chirp instead of
   a trill, and the whole model sounds thin.
3. **The call-unit length must be measured on the note's own timescale.** The
   insect rule (threshold the raw envelope, take the median run) finds a 1.5 ms
   tooth strike. Applied to an owl it finds the 3 ms wiggles riding on a 250 ms
   hoot, and the owl ships as a click. `UNIT_SHAPE` smooths the envelope to the
   note timescale per taxon and floors the unit length (owls 120 ms, doves
   100 ms, squirrels 20 ms, woodpeckers 15 ms, bats 3 ms).

## Hearing it without the rig

```bash
python -m sensepi.sonification.chorus.preview                      # newest recording
python -m sensepi.sonification.chorus.preview <session_dir> --map 3f-base --only owls birds
```

writes `output/sonification/previews/<recording>_<stamp>/preview_<config>.wav` and a
report of which species each eigenfrequency picked per animal type.

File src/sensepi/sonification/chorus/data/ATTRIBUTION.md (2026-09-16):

# Bioacoustic sample dataset — attribution

Source: iNaturalist (https://www.inaturalist.org), public API.
Timbre source material for the SensePi bioacoustic sonification model.
**Non-commercial research use.** CC-BY family licences require that the
attribution below be preserved wherever this material is redistributed.

375 recordings, 121 shipped species, 117.3 MB of source audio. The full download list is in `dataset/ATTRIBUTION_full.md`.

| Species | Type | Common name | Licence | Observer | Observation |
|---|---|---|---|---|---|
| _Austronomus australis_ | bats | White-striped Free-tailed Bat | CC-BY-NC | Antoni Camozzato | https://www.inaturalist.org/observations/330569135 |
| _Austronomus australis_ | bats | White-striped Free-tailed Bat | CC-BY-NC | eco_erin | https://www.inaturalist.org/observations/61470947 |
| _Austronomus australis_ | bats | White-striped Free-tailed Bat | CC-BY-NC | caliginous | https://www.inaturalist.org/observations/190567014 |
| _Cnephaeus nilssonii_ | bats | Northern Serotine | CC-BY-NC | Juha Kinnunen | https://www.inaturalist.org/observations/50093186 |
| _Cnephaeus nilssonii_ | bats | Northern Serotine | CC-BY-NC | Juha Kinnunen | https://www.inaturalist.org/observations/48952204 |
| _Cnephaeus nilssonii_ | bats | Northern Serotine | CC-BY-NC | Juha Kinnunen | https://www.inaturalist.org/observations/48951156 |
| _Epomophorus gambianus_ | bats | Gambian Epauletted Fruit Bat | CC-BY-NC | bolare | https://www.inaturalist.org/observations/33800610 |
| _Epomophorus wahlbergi_ | bats | Wahlberg's Epauletted Fruit Bat | CC-BY-NC | Sally Adam | https://www.inaturalist.org/observations/34407046 |
| _Epomophorus wahlbergi_ | bats | Wahlberg's Epauletted Fruit Bat | CC-BY-SA | Suvarna Parbhoo Mohan | https://www.inaturalist.org/observations/226902012 |
| _Epomophorus wahlbergi_ | bats | Wahlberg's Epauletted Fruit Bat | CC-BY-NC | Peter Vos | https://www.inaturalist.org/observations/42727026 |
| _Eptesicus fuscus_ | bats | Big Brown Bat | CC-BY-NC | arkaen | https://www.inaturalist.org/observations/266609002 |
| _Eptesicus fuscus_ | bats | Big Brown Bat | CC-BY-NC | arkaen | https://www.inaturalist.org/observations/266609002 |
| _Eptesicus fuscus_ | bats | Big Brown Bat | CC-BY-NC | arkaen | https://www.inaturalist.org/observations/266609002 |
| _Eumops bonariensis_ | bats | Dwarf Bonneted Bat | CC-BY-NC | Franco Palandri | https://www.inaturalist.org/observations/330582057 |
| _Eumops bonariensis_ | bats | Dwarf Bonneted Bat | CC-BY-NC | Franco Palandri | https://www.inaturalist.org/observations/330582057 |
| _Hypsignathus monstrosus_ | bats | Hammer-headed Fruit Bat | CC-BY-NC | Frank Willems | https://www.inaturalist.org/observations/247472126 |
| _Myotis dasycneme_ | bats | pond bat | CC-BY-NC | Федор Кондрачук | https://www.inaturalist.org/observations/167596591 |
| _Myotis dasycneme_ | bats | pond bat | CC-BY-NC | Федор Кондрачук | https://www.inaturalist.org/observations/167596591 |
| _Myotis dasycneme_ | bats | pond bat | CC-BY-NC | Федор Кондрачук | https://www.inaturalist.org/observations/167596591 |
| _Pipistrellus pipistrellus_ | bats | Common Pipistrelle | CC-BY-NC | Stefano Doglio | https://www.inaturalist.org/observations/162286355 |
| _Pipistrellus pipistrellus_ | bats | Common Pipistrelle | CC-BY-NC | Friends of Rising Sun Country Park | https://www.inaturalist.org/observations/157466038 |
| _Pipistrellus pipistrellus_ | bats | Common Pipistrelle | CC-BY-NC | olliedav | https://www.inaturalist.org/observations/74663351 |
| _Pipistrellus pygmaeus_ | bats | Soprano Pipistrelle | CC-BY | Denis Forzy | https://www.inaturalist.org/observations/396497855 |
| _Pipistrellus pygmaeus_ | bats | Soprano Pipistrelle | CC-BY-NC | Leo Grosche | https://www.inaturalist.org/observations/389105754 |
| _Rhinolophus hipposideros_ | bats | Lesser Horseshoe Bat | CC-BY-NC | alcon_blue | https://www.inaturalist.org/observations/231172262 |
| _Rhinolophus hipposideros_ | bats | Lesser Horseshoe Bat | CC-BY-NC | alcon_blue | https://www.inaturalist.org/observations/231172262 |
| _Tadarida teniotis_ | bats | European Free-tailed Bat | CC-BY-NC | Goro Saber Animal | https://www.inaturalist.org/observations/266430642 |
| _Tadarida teniotis_ | bats | European Free-tailed Bat | CC-BY-NC | Julien Bottinelli | https://www.inaturalist.org/observations/116679469 |
| _Carineta diardi_ | cicadas |  | CC-BY-NC | Observações Naturalistas | Bruno Uehara | https://www.inaturalist.org/observations/139008401 |
| _Carineta diardi_ | cicadas |  | CC-BY-NC | Matheus M. Santos | https://www.inaturalist.org/observations/138368603 |
| _Carineta diardi_ | cicadas |  | CC-BY-NC | Observações Naturalistas | Bruno Uehara | https://www.inaturalist.org/observations/139008401 |
| _Carineta diardi_ | cicadas |  | CC-BY-NC | Matheus M. Santos | https://www.inaturalist.org/observations/138368603 |
| _Carineta diardi_ | cicadas |  | CC-BY-NC | vinicius_s_domingues | https://www.inaturalist.org/observations/251102829 |
| _Hewlettia nigriviridis_ | cicadas |  | CC-BY-NC | James Bailey | https://www.inaturalist.org/observations/27962501 |
| _Hewlettia nigriviridis_ | cicadas |  | CC-BY-NC | James Bailey | https://www.inaturalist.org/observations/27962501 |
| _Hewlettia nigriviridis_ | cicadas |  | CC-BY-NC | Elliott Smeds | https://www.inaturalist.org/observations/122363597 |
| _Hilaphura varipes_ | cicadas |  | CC-BY-NC | cigarras_de_portugal | https://www.inaturalist.org/observations/38506777 |
| _Hilaphura varipes_ | cicadas |  | CC-BY | Pedro Eça | https://www.inaturalist.org/observations/368593661 |
| _Macrotristria angularis_ | cicadas | Cherrynose | CC-BY-NC | Ben McBurney | https://www.inaturalist.org/observations/69183549 |
| _Macrotristria angularis_ | cicadas | Cherrynose | CC-BY-NC | Colin Trainor | https://www.inaturalist.org/observations/200129780 |
| _Megapomponia merula_ | cicadas |  | CC-BY-NC | ChanSK | https://www.inaturalist.org/observations/94432338 |
| _Megapomponia merula_ | cicadas |  | CC-BY | Gijs Romijn | https://www.inaturalist.org/observations/163887448 |
| _Monomatapa insignis_ | cicadas | Large Widehead Cicada | CC-BY-NC | Dewald du Plessis | https://www.inaturalist.org/observations/35983086 |
| _Monomatapa insignis_ | cicadas | Large Widehead Cicada | CC-BY-NC | Dewald du Plessis | https://www.inaturalist.org/observations/35983086 |
| _Monomatapa insignis_ | cicadas | Large Widehead Cicada | CC-BY-NC | Dewald du Plessis | https://www.inaturalist.org/observations/35857882 |
| _Okanagana opacipennis_ | cicadas | manzanita cicada | CC-BY-NC | James Bailey | https://www.inaturalist.org/observations/26717973 |
| _Okanagana opacipennis_ | cicadas | manzanita cicada | CC-BY-NC | James Bailey | https://www.inaturalist.org/observations/26717973 |
| _Okanagana opacipennis_ | cicadas | manzanita cicada | CC-BY-NC | Elliott Smeds | https://www.inaturalist.org/observations/122363615 |
| _Quesada gigas_ | cicadas | Giant Cicada | CC-BY | Helio Lourencini | https://www.inaturalist.org/observations/111993301 |
| _Quesada gigas_ | cicadas | Giant Cicada | CC-BY-NC | Rachel G | https://www.inaturalist.org/observations/88071479 |
| _Tibicina haematodes_ | cicadas | Red Cicada | CC-BY | Stanislav Murashkin | https://www.inaturalist.org/observations/227045105 |
| _Tibicina haematodes_ | cicadas | Red Cicada | CC-BY-NC | tamaszeke | https://www.inaturalist.org/observations/170997785 |
| _Tibicina haematodes_ | cicadas | Red Cicada | CC-BY | Stanislav Murashkin | https://www.inaturalist.org/observations/227045105 |
| _Tibicina haematodes_ | cicadas | Red Cicada | CC-BY-NC | tamaszeke | https://www.inaturalist.org/observations/170997785 |
| _Yezoterpnosia nigricosta_ | cicadas | Ezo Spring Cicada | CC-BY-NC | Steven Kurniawidjaja | https://www.inaturalist.org/observations/9626955 |
| _Yezoterpnosia nigricosta_ | cicadas | Ezo Spring Cicada | CC-BY-NC | Alexander Yakovlev | https://www.inaturalist.org/observations/69463414 |
| _Anurogryllus celerinictus_ | crickets | Indies Short-tailed Cricket | CC-BY | David Garza | https://www.inaturalist.org/observations/150865338 |
| _Anurogryllus celerinictus_ | crickets | Indies Short-tailed Cricket | CC-BY-NC | Chalon Boesel | https://www.inaturalist.org/observations/97121532 |
| _Gryllus assimilis_ | crickets | Jamaican Field Cricket | CC-BY-NC | Antônio | https://www.inaturalist.org/observations/116252739 |
| _Gryllus assimilis_ | crickets | Jamaican Field Cricket | CC-BY-NC | Theodor Igor Ottinger | https://www.inaturalist.org/observations/295562642 |
| _Gryllus assimilis_ | crickets | Jamaican Field Cricket | CC-BY-NC | Cin-Ty Lee | https://www.inaturalist.org/observations/62271051 |
| _Gryllus campestris_ | crickets | European Field Cricket | CC0 | Marino Linić | https://www.inaturalist.org/observations/219272343 |
| _Gryllus campestris_ | crickets | European Field Cricket | CC-BY-NC | Frank Fritzlar | https://www.inaturalist.org/observations/304282015 |
| _Gryllus campestris_ | crickets |  | CC-BY-NC (SEE INATURALIST) | see iNaturalist |  |
| _Gryllus campestris_ | crickets |  | CC-BY-NC (SEE INATURALIST) | see iNaturalist |  |
| _Gryllus campestris_ | crickets | European Field Cricket | CC0 | Marino Linić | https://www.inaturalist.org/observations/219272343 |
| _Gryllus campestris_ | crickets | European Field Cricket | CC-BY-NC | Frank Fritzlar | https://www.inaturalist.org/observations/304282015 |
| _Gryllus campestris_ | crickets | European Field Cricket | CC-BY-NC | Karsten Mody | https://www.inaturalist.org/observations/356803373 |
| _Lepidogryllus parvulus_ | crickets |  | CC-BY | Shaun Lee | https://www.inaturalist.org/observations/111362531 |
| _Lepidogryllus parvulus_ | crickets |  | CC-BY | Shaun Lee | https://www.inaturalist.org/observations/111362531 |
| _Lepidogryllus parvulus_ | crickets |  | CC-BY | Shaun Lee | https://www.inaturalist.org/observations/111362531 |
| _Lepidogryllus parvulus_ | crickets |  | CC-BY | Shaun Lee | https://www.inaturalist.org/observations/111362531 |
| _Lepidogryllus parvulus_ | crickets |  | CC-BY | Shaun Lee | https://www.inaturalist.org/observations/111362531 |
| _Loxoblemmus arietulus_ | crickets |  | CC-BY-NC | Observações Naturalistas | Bruno Uehara | https://www.inaturalist.org/observations/99345793 |
| _Loxoblemmus arietulus_ | crickets |  | CC-BY-NC | Observações Naturalistas | Bruno Uehara | https://www.inaturalist.org/observations/96266504 |
| _Loxoblemmus doenitzi_ | crickets |  | CC-BY-NC | snipecube3d | https://www.inaturalist.org/observations/305213383 |
| _Loxoblemmus doenitzi_ | crickets |  | CC-BY-NC | Observações Naturalistas | Bruno Uehara | https://www.inaturalist.org/observations/99341655 |
| _Loxoblemmus doenitzi_ | crickets |  | CC-BY-NC | orientalstork | https://www.inaturalist.org/observations/305993858 |
| _Neoxabea bipunctata_ | crickets | Two-spotted Tree Cricket | CC-BY-NC | Kyle Aldinger | https://www.inaturalist.org/observations/236638147 |
| _Neoxabea bipunctata_ | crickets | Two-spotted Tree Cricket | CC-BY-NC | David H Small | https://www.inaturalist.org/observations/57599334 |
| _Neoxabea bipunctata_ | crickets | Two-spotted Tree Cricket | CC-BY-NC | Chelsea Clifford | https://www.inaturalist.org/observations/231318417 |
| _Oecanthus angustus_ | crickets | Common Tree Cricket | CC-BY-NC | simono | https://www.inaturalist.org/observations/52247911 |
| _Oecanthus angustus_ | crickets | Common Tree Cricket | CC-BY-NC | simono | https://www.inaturalist.org/observations/56497666 |
| _Oecanthus angustus_ | crickets | Common Tree Cricket | CC-BY-NC | simono | https://www.inaturalist.org/observations/56497176 |
| _Oecanthus beameri_ | crickets | White Sands Tree Cricket | CC-BY-NC | James Bailey | https://www.inaturalist.org/observations/102287655 |
| _Oecanthus beameri_ | crickets | White Sands Tree Cricket | CC-BY | Jared Shorma | https://www.inaturalist.org/observations/98434363 |
| _Oecanthus beameri_ | crickets | White Sands Tree Cricket | CC-BY | Jared Shorma | https://www.inaturalist.org/observations/98434363 |
| _Oecanthus dulcisonans_ | crickets | Large Tree-cricket | CC-BY-NC | lvdr | https://www.inaturalist.org/observations/139242796 |
| _Oecanthus dulcisonans_ | crickets | Large Tree-cricket | CC-BY-NC | robsouter | https://www.inaturalist.org/observations/250023148 |
| _Oecanthus dulcisonans_ | crickets | Large Tree-cricket | CC-BY-NC | Pedro Beja | https://www.inaturalist.org/observations/125841461 |
| _Oecanthus fultoni_ | crickets | Snowy Tree Cricket | CC-BY-NC | Dom | https://www.inaturalist.org/observations/308588489 |
| _Oecanthus fultoni_ | crickets | Snowy Tree Cricket | CC-BY-NC | Amcilraith | https://www.inaturalist.org/observations/182718632 |
| _Oecanthus fultoni_ | crickets | Snowy Tree Cricket | CC-BY-NC | Froggy Elizabeth Tinker | https://www.inaturalist.org/observations/304647720 |
| _Oecanthus fultoni_ | crickets | Snowy Tree Cricket | CC-BY-NC | Dom | https://www.inaturalist.org/observations/308588489 |
| _Oecanthus niveus_ | crickets | Narrow-winged Tree Cricket | CC-BY-NC | Kyle Aldinger | https://www.inaturalist.org/observations/236638243 |
| _Oecanthus niveus_ | crickets | Narrow-winged Tree Cricket | CC-BY | Dan Johnson | https://www.inaturalist.org/observations/219688419 |
| _Oecanthus niveus_ | crickets | Narrow-winged Tree Cricket | CC-BY-NC | bertfoquet | https://www.inaturalist.org/observations/375116408 |
| _Svercus palmetorum_ | crickets | Cicada Cricket | CC-BY-NC | Axel Gosseries | https://www.inaturalist.org/observations/206021429 |
| _Svercus palmetorum_ | crickets | Cicada Cricket | CC-BY-NC | Axel Gosseries | https://www.inaturalist.org/observations/206021429 |
| _Svercus palmetorum_ | crickets |  | CC-BY-NC (SEE INATURALIST) | see iNaturalist |  |
| _Svercus palmetorum_ | crickets |  | CC-BY-NC (SEE INATURALIST) | see iNaturalist |  |
| _Svercus palmetorum_ | crickets | Cicada Cricket | CC-BY-NC | Axel Gosseries | https://www.inaturalist.org/observations/206021429 |
| _Svercus palmetorum_ | crickets | Cicada Cricket | CC-BY-NC | Axel Gosseries | https://www.inaturalist.org/observations/206021429 |
| _Svercus palmetorum_ | crickets | Cicada Cricket | CC-BY-NC | Loïs Rancilhac | https://www.inaturalist.org/observations/170814473 |
| _Velarifictorus aspersus_ | crickets |  | CC-BY-NC | 醉翁 | https://www.inaturalist.org/observations/81796492 |
| _Velarifictorus aspersus_ | crickets |  | CC-BY | smathichong | https://www.inaturalist.org/observations/361565159 |
| _Velarifictorus ornatus_ | crickets |  | CC-BY-NC | 维生素 | https://www.inaturalist.org/observations/282377455 |
| _Velarifictorus ornatus_ | crickets |  | CC-BY-NC | wresy | https://www.inaturalist.org/observations/293366233 |
| _Velarifictorus ornatus_ | crickets |  | CC-BY-NC | 维生素 | https://www.inaturalist.org/observations/294820568 |
| _Claravis pretiosa_ | doves | Blue Ground Dove | CC-BY-NC | Breno Farias | https://www.inaturalist.org/observations/362550343 |
| _Claravis pretiosa_ | doves | Blue Ground Dove | CC-BY-NC | dbeadle | https://www.inaturalist.org/observations/259194789 |
| _Claravis pretiosa_ | doves | Blue Ground Dove | CC-BY-NC | dbeadle | https://www.inaturalist.org/observations/259194789 |
| _Columba leucomela_ | doves | White-headed Pigeon | CC-BY-NC | rosewise | https://www.inaturalist.org/observations/196409902 |
| _Columba leucomela_ | doves | White-headed Pigeon | CC-BY-NC | heathercoffs | https://www.inaturalist.org/observations/201174670 |
| _Columba leucomela_ | doves | White-headed Pigeon | CC-BY-NC | heathercoffs | https://www.inaturalist.org/observations/201174670 |
| _Columbina squammata_ | doves | Scaled Dove | CC-BY-NC | Evandro Mariano | https://www.inaturalist.org/observations/192947496 |
| _Columbina squammata_ | doves | Scaled Dove | CC-BY-NC | Alejandro Luy | https://www.inaturalist.org/observations/197980177 |
| _Columbina squammata_ | doves | Scaled Dove | CC-BY-NC | Alejandro Luy | https://www.inaturalist.org/observations/197980177 |
| _Leucosarcia melanoleuca_ | doves | Wonga Pigeon | CC-BY-NC | funky_drewster | https://www.inaturalist.org/observations/104690512 |
| _Leucosarcia melanoleuca_ | doves | Wonga Pigeon | CC-BY-NC | Reiner Richter | https://www.inaturalist.org/observations/102398936 |
| _Leucosarcia melanoleuca_ | doves | Wonga Pigeon | CC-BY-NC | urungaroger | https://www.inaturalist.org/observations/192330590 |
| _Macropygia phasianella_ | doves | Brown Cuckoo-Dove | CC-BY-NC | pratyeka | https://www.inaturalist.org/observations/199314684 |
| _Macropygia phasianella_ | doves | Brown Cuckoo-Dove | CC-BY-NC | hlogie | https://www.inaturalist.org/observations/298014632 |
| _Macropygia phasianella_ | doves | Brown Cuckoo-Dove | CC-BY-NC | Margaret Sky | https://www.inaturalist.org/observations/90726497 |
| _Patagioenas picazuro_ | doves | Picazuro Pigeon | CC-BY-NC | paupitz | https://www.inaturalist.org/observations/179386163 |
| _Patagioenas picazuro_ | doves | Picazuro Pigeon | CC-BY-NC | Carlos Pontes | https://www.inaturalist.org/observations/367673736 |
| _Patagioenas picazuro_ | doves | Picazuro Pigeon | CC-BY-NC | Gonzalo Diaz | https://www.inaturalist.org/observations/146868004 |
| _Phaps chalcoptera_ | doves | Common Bronzewing | CC-BY-NC | Tanveer Alvi | https://www.inaturalist.org/observations/192175082 |
| _Phaps chalcoptera_ | doves | Common Bronzewing | CC-BY | Ian Rainbow | https://www.inaturalist.org/observations/197051043 |
| _Phaps chalcoptera_ | doves | Common Bronzewing | CC-BY-NC | Vermilingua_pygmaeus | https://www.inaturalist.org/observations/199933229 |
| _Spilopelia senegalensis_ | doves | Laughing Dove | CC-BY-NC | Ila France | https://www.inaturalist.org/observations/77300129 |
| _Spilopelia senegalensis_ | doves | Laughing Dove | CC-BY-NC | dbeadle | https://www.inaturalist.org/observations/177657931 |
| _Spilopelia senegalensis_ | doves | Laughing Dove | CC-BY-NC | hugoyann | https://www.inaturalist.org/observations/346733309 |
| _Streptopelia orientalis_ | doves | Oriental Turtle-Dove | CC-BY | IMORI MIHO | https://www.inaturalist.org/observations/257186985 |
| _Streptopelia orientalis_ | doves | Oriental Turtle-Dove | CC-BY-NC | sala_mandur_luvr | https://www.inaturalist.org/observations/340704652 |
| _Streptopelia orientalis_ | doves | Oriental Turtle-Dove | CC-BY-NC | sala_mandur_luvr | https://www.inaturalist.org/observations/340704652 |
| _Zenaida macroura_ | doves | Mourning Dove | CC-BY-NC | Ray Snook | https://www.inaturalist.org/observations/380711583 |
| _Zenaida macroura_ | doves | Mourning Dove | CC-BY-NC | dluciano | https://www.inaturalist.org/observations/71819689 |
| _Zenaida macroura_ | doves | Mourning Dove | CC-BY-NC | mixxiechick | https://www.inaturalist.org/observations/369726444 |
| _Cacosternum parvum_ | frogs | Mountain caco | CC-BY-NC | Tim Brammer | https://www.inaturalist.org/observations/338211611 |
| _Cacosternum parvum_ | frogs | Mountain caco | CC-BY-NC | Adriaan Jordaan | https://www.inaturalist.org/observations/191458230 |
| _Dryophytes chrysoscelis_ | frogs | Cope's Gray Tree Frog | CC-BY-NC | sglanville | https://www.inaturalist.org/observations/81103830 |
| _Dryophytes chrysoscelis_ | frogs | Cope's Gray Tree Frog | CC-BY-NC | JoshExistsToo | https://www.inaturalist.org/observations/338998854 |
| _Epidalea calamita_ | frogs | Natterjack Toad | CC-BY-NC | Axel Gosseries | https://www.inaturalist.org/observations/146143308 |
| _Epidalea calamita_ | frogs | Natterjack Toad | CC-BY-NC | Axel Gosseries | https://www.inaturalist.org/observations/146143308 |
| _Heleophryne depressa_ | frogs | Cederberg Ghost Frog | CC-BY-NC | Alex Rebelo | https://www.inaturalist.org/observations/9142273 |
| _Heleophryne depressa_ | frogs | Cederberg Ghost Frog | CC-BY-NC | Nick Helme | https://www.inaturalist.org/observations/63748397 |
| _Heleophryne depressa_ | frogs | Cederberg Ghost Frog | CC-BY-NC | Nick Helme | https://www.inaturalist.org/observations/63748397 |
| _Hyla arborea_ | frogs | European Tree Frog | CC-BY-NC | Stamatis Kalogiannis | https://www.inaturalist.org/observations/254517550 |
| _Hyla arborea_ | frogs | European Tree Frog | CC-BY | Igor Balashov | https://www.inaturalist.org/observations/168146835 |
| _Lithobates catesbeianus_ | frogs | American Bullfrog | CC-BY-NC | Ty Smith | https://www.inaturalist.org/observations/97524274 |
| _Lithobates catesbeianus_ | frogs |  | CC-BY-NC (SEE INATURALIST) | see iNaturalist |  |
| _Lithobates catesbeianus_ | frogs | American Bullfrog | CC-BY-NC | Ty Smith | https://www.inaturalist.org/observations/97524274 |
| _Lithobates catesbeianus_ | frogs | American Bullfrog | CC-BY-NC | hmung013 | https://www.inaturalist.org/observations/362174668 |
| _Lithobates kauffeldi_ | frogs | Atlantic Coast Leopard Frog | CC-BY-NC | Ty Smith | https://www.inaturalist.org/observations/70929826 |
| _Lithobates kauffeldi_ | frogs | Atlantic Coast Leopard Frog | CC0 | Eric Bartkowski | https://www.inaturalist.org/observations/153179156 |
| _Pelophylax perezi_ | frogs | Iberian Green Frog | CC-BY-NC | Daniel Gaona Carrilero | https://www.inaturalist.org/observations/159880015 |
| _Pelophylax perezi_ | frogs | Iberian Green Frog | CC-BY-NC | Daniel Gaona Carrilero | https://www.inaturalist.org/observations/159880015 |
| _Peltophryne lemur_ | frogs | Puerto Rican Crested Toad | CC-BY-NC | Wilfredo Falcon | https://www.inaturalist.org/observations/9882466 |
| _Peltophryne lemur_ | frogs |  | CC-BY-NC (SEE INATURALIST) | see iNaturalist |  |
| _Peltophryne lemur_ | frogs | Puerto Rican Crested Toad | CC-BY-NC | Wilfredo Falcon | https://www.inaturalist.org/observations/9882466 |
| _Pseudacris brachyphona_ | frogs | Mountain Chorus Frog | CC-BY-NC | Sara Spaid | https://www.inaturalist.org/observations/207509153 |
| _Pseudacris brachyphona_ | frogs | Mountain Chorus Frog | CC-BY-NC | Sara Spaid | https://www.inaturalist.org/observations/114374405 |
| _Pseudacris brachyphona_ | frogs | Mountain Chorus Frog | CC-BY-NC | michael_hodge | https://www.inaturalist.org/observations/268310558 |
| _Pseudacris kalmi_ | frogs | New Jersey Chorus Frog | CC-BY-NC | Ty Smith | https://www.inaturalist.org/observations/72147316 |
| _Rhinella horribilis_ | frogs | Giant Toad | CC-BY-NC | Chris Harrison | https://www.inaturalist.org/observations/6832635 |
| _Sclerophrys pardalis_ | frogs | Eastern Leopard Toad | CC-BY-NC | Adam Welz | https://www.inaturalist.org/observations/178415600 |
| _Tomopterna adiastola_ | frogs | Confused Sand frog | CC-BY-NC | Jacob Dirsuwei | https://www.inaturalist.org/observations/102584519 |
| _Tomopterna adiastola_ | frogs |  | CC-BY-NC (SEE INATURALIST) | see iNaturalist |  |
| _Tomopterna adiastola_ | frogs | Confused Sand frog | CC-BY-NC | Jacob Dirsuwei | https://www.inaturalist.org/observations/102584519 |
| _Tomopterna delalandii_ | frogs | Cape sand frog | CC-BY-NC | robertwelsh | https://www.inaturalist.org/observations/95983282 |
| _Tomopterna delalandii_ | frogs | Cape sand frog | CC-BY-NC | robertwelsh | https://www.inaturalist.org/observations/95983282 |
| _Tomopterna delalandii_ | frogs | Cape sand frog | CC-BY-NC | robertwelsh | https://www.inaturalist.org/observations/95983282 |
| _Tomopterna delalandii_ | frogs | Cape sand frog | CC-BY-NC | robertwelsh | https://www.inaturalist.org/observations/95983282 |
| _Tomopterna delalandii_ | frogs | Cape sand frog | CC-BY-NC | Nick Helme | https://www.inaturalist.org/observations/106665105 |
| _Aglaothorax amathitis_ | grasshoppers | Bluffs Shieldback | CC-BY-NC | James Bailey | https://www.inaturalist.org/observations/86134427 |
| _Chorthippus biguttulus_ | grasshoppers | Bow-winged Grasshopper | CC-BY-NC | Karol Łanocha | https://www.inaturalist.org/observations/243564797 |
| _Chorthippus biguttulus_ | grasshoppers | Bow-winged Grasshopper | CC-BY-NC | Simon Bertschy | https://www.inaturalist.org/observations/130384498 |
| _Chorthippus biguttulus_ | grasshoppers | Bow-winged Grasshopper | CC-BY-NC | gernotkunz | https://www.inaturalist.org/observations/225903522 |
| _Chortophaga viridifasciata_ | grasshoppers | Green-striped Grasshopper | CC0 | kristinpiston | https://www.inaturalist.org/observations/228270375 |
| _Chortophaga viridifasciata_ | grasshoppers | Green-striped Grasshopper | CC0 | kristinpiston | https://www.inaturalist.org/observations/228270375 |
| _Chortophaga viridifasciata_ | grasshoppers | Green-striped Grasshopper | CC-BY-NC | F Dylan Titmuss | https://www.inaturalist.org/observations/114040536 |
| _Gryllodes sigillatus_ | grasshoppers | Tropical House Cricket | CC-BY-NC | Joseph Knight | https://www.inaturalist.org/observations/360812681 |
| _Gryllodes sigillatus_ | grasshoppers | Tropical House Cricket | CC-BY-NC | James Bailey | https://www.inaturalist.org/observations/111376907 |
| _Gryllodes sigillatus_ | grasshoppers | Tropical House Cricket | CC-BY-NC | david26781 | https://www.inaturalist.org/observations/109872267 |
| _Gryllodes sigillatus_ | grasshoppers | Tropical House Cricket | CC-BY-NC | Joseph Knight | https://www.inaturalist.org/observations/360812681 |
| _Gryllodes sigillatus_ | grasshoppers | Tropical House Cricket | CC-BY-NC | James Bailey | https://www.inaturalist.org/observations/111376907 |
| _Megaulacobothrus aethalinus_ | grasshoppers |  | CC-BY | Олег Кудров | https://www.inaturalist.org/observations/91078940 |
| _Megaulacobothrus aethalinus_ | grasshoppers |  | CC-BY | Олег Кудров | https://www.inaturalist.org/observations/91078940 |
| _Megaulacobothrus aethalinus_ | grasshoppers |  | CC-BY | Олег Кудров | https://www.inaturalist.org/observations/91078940 |
| _Megaulacobothrus aethalinus_ | grasshoppers |  | CC-BY | Олег Кудров | https://www.inaturalist.org/observations/91078940 |
| _Megaulacobothrus aethalinus_ | grasshoppers |  | CC-BY | Олег Кудров | https://www.inaturalist.org/observations/91078940 |
| _Meloimorpha japonica_ | grasshoppers | Asian Bell Cricket | CC-BY-NC | rdrl | https://www.inaturalist.org/observations/181913180 |
| _Meloimorpha japonica_ | grasshoppers | Asian Bell Cricket | CC-BY-NC | rdrl | https://www.inaturalist.org/observations/181913180 |
| _Omocestus rufipes_ | grasshoppers | Woodland Grasshopper | CC-BY-NC | Joachim Wimmer | https://www.inaturalist.org/observations/87521802 |
| _Omocestus rufipes_ | grasshoppers | Woodland Grasshopper | CC-BY-NC | Romain BAGHI | https://www.inaturalist.org/observations/313962259 |
| _Omocestus rufipes_ | grasshoppers | Woodland Grasshopper | CC-BY-NC | melissa-garcia | https://www.inaturalist.org/observations/278927422 |
| _Podismopsis poppiusi_ | grasshoppers |  | CC-BY | Олег Кудров | https://www.inaturalist.org/observations/66080859 |
| _Podismopsis poppiusi_ | grasshoppers |  | CC-BY | Олег Кудров | https://www.inaturalist.org/observations/87869016 |
| _Podismopsis poppiusi_ | grasshoppers |  | CC-BY | Олег Кудров | https://www.inaturalist.org/observations/87869016 |
| _Stethophyma grossum_ | grasshoppers | Large Marsh Grasshopper | CC-BY-NC | mobbini | https://www.inaturalist.org/observations/340635753 |
| _Stethophyma grossum_ | grasshoppers | Large Marsh Grasshopper | CC-BY-NC | mobbini | https://www.inaturalist.org/observations/340635753 |
| _Stethophyma grossum_ | grasshoppers | Large Marsh Grasshopper | CC-BY-NC | Phaulactis | https://www.inaturalist.org/observations/89830044 |
| _Velarifictorus micado_ | grasshoppers | Japanese Burrowing Cricket | CC-BY-NC | onidiras-iNaturalist | https://www.inaturalist.org/observations/135314542 |
| _Velarifictorus micado_ | grasshoppers | Japanese Burrowing Cricket | CC-BY-NC | onidiras-iNaturalist | https://www.inaturalist.org/observations/133540347 |
| _Velarifictorus micado_ | grasshoppers | Japanese Burrowing Cricket | CC-BY-NC | onidiras-iNaturalist | https://www.inaturalist.org/observations/135314542 |
| _Velarifictorus micado_ | grasshoppers | Japanese Burrowing Cricket | CC-BY-NC | onidiras-iNaturalist | https://www.inaturalist.org/observations/133540347 |
| _Velarifictorus micado_ | grasshoppers | Japanese Burrowing Cricket | CC-BY | L.J. Lamera | https://www.inaturalist.org/observations/226493575 |
| _Velarifictorus micado_ | grasshoppers | Japanese Burrowing Cricket | CC-BY-NC | onidiras-iNaturalist | https://www.inaturalist.org/observations/135314542 |
| _Velarifictorus micado_ | grasshoppers | Japanese Burrowing Cricket | CC-BY-NC | onidiras-iNaturalist | https://www.inaturalist.org/observations/133540347 |
| _Aglaothorax ovatus_ | katydids | Ovate Shieldback | CC-BY-NC | James Bailey | https://www.inaturalist.org/observations/170455208 |
| _Aglaothorax ovatus_ | katydids | Ovate Shieldback | CC-BY-NC | James Bailey | https://www.inaturalist.org/observations/170455208 |
| _Aglaothorax ovatus_ | katydids | Ovate Shieldback | CC-BY-NC | James Bailey | https://www.inaturalist.org/observations/170455208 |
| _Aglaothorax ovatus_ | katydids | Ovate Shieldback | CC-BY-NC | James Bailey | https://www.inaturalist.org/observations/170455208 |
| _Aglaothorax ovatus_ | katydids | Ovate Shieldback | CC-BY-NC | James Bailey | https://www.inaturalist.org/observations/170455414 |
| _Aglaothorax ovatus_ | katydids | Ovate Shieldback | CC-BY-NC | James Bailey | https://www.inaturalist.org/observations/170455208 |
| _Aglaothorax ovatus_ | katydids | Ovate Shieldback | CC-BY-NC | James Bailey | https://www.inaturalist.org/observations/170455208 |
| _Amblycorypha oblongifolia_ | katydids | Oblong-winged Katydid | CC-BY-NC | Austin | https://www.inaturalist.org/observations/230844856 |
| _Amblycorypha oblongifolia_ | katydids | Oblong-winged Katydid | CC-BY-NC | Austin | https://www.inaturalist.org/observations/230840988 |
| _Amblycorypha oblongifolia_ | katydids | Oblong-winged Katydid | CC-BY-NC | Vicki McKay | https://www.inaturalist.org/observations/316211419 |
| _Decticus albifrons_ | katydids | White-faced Bush-cricket | CC-BY-NC | Juanvi | https://www.inaturalist.org/observations/29926132 |
| _Decticus albifrons_ | katydids | White-faced Bush-cricket | CC-BY | Roman | https://www.inaturalist.org/observations/16690198 |
| _Decticus albifrons_ | katydids | White-faced Bush-cricket | CC-BY-NC | flamelnico | https://www.inaturalist.org/observations/179872178 |
| _Decticus verrucivorus_ | katydids | Wart-biter | CC-BY | snaily_naily | https://www.inaturalist.org/observations/87831064 |
| _Decticus verrucivorus_ | katydids | Wart-biter | CC-BY-NC | Miriam Öttl | https://www.inaturalist.org/observations/298116596 |
| _Decticus verrucivorus_ | katydids | Wart-biter | CC-BY-NC | Miriam Öttl | https://www.inaturalist.org/observations/298116596 |
| _Hexacentrus mundurra_ | katydids | Fierce Predatory Katydid | CC-BY-NC | simono | https://www.inaturalist.org/observations/39794250 |
| _Hexacentrus mundurra_ | katydids | Fierce Predatory Katydid | CC-BY-NC | Colin Trainor | https://www.inaturalist.org/observations/264780525 |
| _Hexacentrus mundurra_ | katydids | Fierce Predatory Katydid | CC-BY-NC | simono | https://www.inaturalist.org/observations/39794250 |
| _Hexacentrus mundurra_ | katydids | Fierce Predatory Katydid | CC-BY-NC | Colin Trainor | https://www.inaturalist.org/observations/264780525 |
| _Hexacentrus mundurra_ | katydids | Fierce Predatory Katydid | CC-BY-NC | peter_yeeles | https://www.inaturalist.org/observations/213934888 |
| _Metrioptera brachyptera_ | katydids | Bog Bush-cricket | CC-BY-NC | Africa Gomez | https://www.inaturalist.org/observations/241123230 |
| _Metrioptera brachyptera_ | katydids | Bog Bush-cricket | CC-BY-NC | Africa Gomez | https://www.inaturalist.org/observations/241123302 |
| _Metrioptera brachyptera_ | katydids | Bog Bush-cricket | CC-BY-NC | Africa Gomez | https://www.inaturalist.org/observations/241123230 |
| _Microcentrum retinerve_ | katydids | Lesser Anglewing | CC-BY-NC | Dan Johnson | https://www.inaturalist.org/observations/16627500 |
| _Microcentrum retinerve_ | katydids | Lesser Anglewing | CC-BY-NC | Abigail Carlson | https://www.inaturalist.org/observations/348612741 |
| _Microcentrum retinerve_ | katydids | Lesser Anglewing | CC-BY-NC | Abigail Carlson | https://www.inaturalist.org/observations/348612741 |
| _Microcentrum rhombifolium_ | katydids | Greater Anglewing | CC-BY-NC | Ethan Kistler | https://www.inaturalist.org/observations/15316155 |
| _Microcentrum rhombifolium_ | katydids | Greater Anglewing | CC-BY-NC | countbayz | https://www.inaturalist.org/observations/243723847 |
| _Microcentrum rhombifolium_ | katydids | Greater Anglewing | CC-BY-NC | zenat8 | https://www.inaturalist.org/observations/312800756 |
| _Neoconocephalus ensiger_ | katydids | Sword-bearing Conehead | CC-BY-NC | Molly Jacobson | https://www.inaturalist.org/observations/150557122 |
| _Neoconocephalus ensiger_ | katydids | Sword-bearing Conehead | CC-BY-NC | bertfoquet | https://www.inaturalist.org/observations/125733395 |
| _Neoconocephalus ensiger_ | katydids | Sword-bearing Conehead | CC-BY-NC | Molly Jacobson | https://www.inaturalist.org/observations/150557122 |
| _Neoconocephalus ensiger_ | katydids | Sword-bearing Conehead | CC-BY-NC | bertfoquet | https://www.inaturalist.org/observations/125733395 |
| _Neoconocephalus ensiger_ | katydids | Sword-bearing Conehead | CC-BY-NC | bassteeth | https://www.inaturalist.org/observations/306376671 |
| _Onconotus servillei_ | katydids |  | CC-BY | Roman | https://www.inaturalist.org/observations/27343115 |
| _Onconotus servillei_ | katydids |  | CC-BY | Roman | https://www.inaturalist.org/observations/27342663 |
| _Orchelimum nigripes_ | katydids | Black-legged Meadow Katydid | CC-BY-NC | Joseph Langlois | https://www.inaturalist.org/observations/94343677 |
| _Orchelimum nigripes_ | katydids | Black-legged Meadow Katydid | CC-BY-NC | joe dziewa | https://www.inaturalist.org/observations/135017461 |
| _Orchelimum nigripes_ | katydids | Black-legged Meadow Katydid | CC-BY-NC | Joseph Langlois | https://www.inaturalist.org/observations/94343677 |
| _Orchelimum nigripes_ | katydids | Black-legged Meadow Katydid | CC-BY-NC | joe dziewa | https://www.inaturalist.org/observations/135017461 |
| _Orchelimum nigripes_ | katydids | Black-legged Meadow Katydid | CC-BY-NC | Davis Harder | https://www.inaturalist.org/observations/135245705 |
| _Paracyrtophyllus robustus_ | katydids | Central Texas Leaf-Katydid | CC-BY-NC | elisadonovan | https://www.inaturalist.org/observations/82624847 |
| _Paracyrtophyllus robustus_ | katydids | Central Texas Leaf-Katydid | CC-BY | Dan Johnson | https://www.inaturalist.org/observations/364604138 |
| _Paracyrtophyllus robustus_ | katydids | Central Texas Leaf-Katydid | CC-BY-NC | elisadonovan | https://www.inaturalist.org/observations/82624847 |
| _Paracyrtophyllus robustus_ | katydids | Central Texas Leaf-Katydid | CC-BY | Dan Johnson | https://www.inaturalist.org/observations/364604138 |
| _Paracyrtophyllus robustus_ | katydids | Central Texas Leaf-Katydid | CC-BY-NC | Mike Quinn, San Marcos | https://www.inaturalist.org/observations/370208386 |
| _Pholidoptera griseoaptera_ | katydids | Dark Bush-cricket | CC-BY-NC | mobbini | https://www.inaturalist.org/observations/148748353 |
| _Pholidoptera griseoaptera_ | katydids | Dark Bush-cricket | CC-BY-NC | Simon Bertschy | https://www.inaturalist.org/observations/130696018 |
| _Pholidoptera griseoaptera_ | katydids | Dark Bush-cricket | CC0 | Nico | https://www.inaturalist.org/observations/181792604 |
| _Ruspolia nitidula_ | katydids | Large Conehead | CC-BY | Sylvain Eichhorn | https://www.inaturalist.org/observations/172906264 |
| _Ruspolia nitidula_ | katydids | Large Conehead | CC-BY-NC | Sylvain G | https://www.inaturalist.org/observations/229063614 |
| _Ruspolia nitidula_ | katydids | Large Conehead | CC-BY-NC | Paweł Radzikowski | https://www.inaturalist.org/observations/306815014 |
| _Tettigonia viridissima_ | katydids | Great Green Bush-cricket | CC-BY-SA | Gilles San Martin | https://www.inaturalist.org/observations/53777269 |
| _Tettigonia viridissima_ | katydids | Great Green Bush-cricket | CC-BY-NC | laauraaaant | https://www.inaturalist.org/observations/57491876 |
| _Tettigonia viridissima_ | katydids |  | CC-BY-NC (SEE INATURALIST) | see iNaturalist |  |
| _Tettigonia viridissima_ | katydids |  | CC-BY-NC (SEE INATURALIST) | see iNaturalist |  |
| _Tettigonia viridissima_ | katydids | Great Green Bush-cricket | CC-BY-SA | Gilles San Martin | https://www.inaturalist.org/observations/53777269 |
| _Tettigonia viridissima_ | katydids | Great Green Bush-cricket | CC-BY-NC | laauraaaant | https://www.inaturalist.org/observations/57491876 |
| _Tettigonia viridissima_ | katydids | Great Green Bush-cricket | CC-BY-NC | Lennart Mak | https://www.inaturalist.org/observations/90071553 |
| _Asio flammeus_ | owls | Short-eared Owl | CC-BY-NC | nacho1998 | https://www.inaturalist.org/observations/187586386 |
| _Asio flammeus_ | owls | Short-eared Owl | CC-BY-NC | nacho1998 | https://www.inaturalist.org/observations/187586386 |
| _Asio flammeus_ | owls | Short-eared Owl | CC-BY-NC | nacho1998 | https://www.inaturalist.org/observations/187586386 |
| _Athene cunicularia_ | owls | Burrowing Owl | CC-BY-NC | Adam Kalab | https://www.inaturalist.org/observations/171990866 |
| _Athene cunicularia_ | owls | Burrowing Owl | CC-BY-NC | karolmalaver | https://www.inaturalist.org/observations/148802985 |
| _Athene cunicularia_ | owls | Burrowing Owl | CC-BY-NC | karolmalaver | https://www.inaturalist.org/observations/148802985 |
| _Bubo magellanicus_ | owls | Lesser Horned Owl | CC-BY-NC | Rigoberto Yáñez | https://www.inaturalist.org/observations/250599061 |
| _Bubo magellanicus_ | owls | Lesser Horned Owl | CC-BY-NC | Hugo Muñoz-Quintana | https://www.inaturalist.org/observations/81985921 |
| _Bubo magellanicus_ | owls | Lesser Horned Owl | CC-BY | Leonardo Mondaca Lara | https://www.inaturalist.org/observations/117668615 |
| _Bubo virginianus_ | owls | Great Horned Owl | CC-BY-NC | Brenna Farrell | https://www.inaturalist.org/observations/220360023 |
| _Bubo virginianus_ | owls | Great Horned Owl | CC-BY-NC | Brenna Farrell | https://www.inaturalist.org/observations/220360023 |
| _Bubo virginianus_ | owls | Great Horned Owl | CC-BY-NC | Brenna Farrell | https://www.inaturalist.org/observations/220360023 |
| _Glaucidium brasilianum_ | owls | Ferruginous Pygmy-Owl | CC-BY-NC | José Gabriel Sodré | https://www.inaturalist.org/observations/261859196 |
| _Glaucidium brasilianum_ | owls | Ferruginous Pygmy-Owl | CC-BY-NC | Oliver Kohler | https://www.inaturalist.org/observations/129430890 |
| _Glaucidium brasilianum_ | owls | Ferruginous Pygmy-Owl | CC-BY | Augusto Guerrante | https://www.inaturalist.org/observations/325103472 |
| _Glaucidium passerinum_ | owls | Eurasian Pygmy-Owl | CC-BY-NC | Aleksey Levashkin | https://www.inaturalist.org/observations/107326878 |
| _Glaucidium passerinum_ | owls | Eurasian Pygmy-Owl | CC-BY-NC | dallenstein | https://www.inaturalist.org/observations/69913328 |
| _Glaucidium passerinum_ | owls | Eurasian Pygmy-Owl | CC-BY-NC | dallenstein | https://www.inaturalist.org/observations/69913328 |
| _Megascops choliba_ | owls | Tropical Screech-Owl | CC-BY | Valentín Alfano | https://www.inaturalist.org/observations/380511738 |
| _Megascops choliba_ | owls | Tropical Screech-Owl | CC-BY-NC | Daniel Alejandro Paiz | https://www.inaturalist.org/observations/255933254 |
| _Megascops choliba_ | owls | Tropical Screech-Owl | CC-BY-NC | Victor | https://www.inaturalist.org/observations/204153593 |
| _Ninox boobook_ | owls | Australian Boobook | CC-BY-NC | Sue Tardif | https://www.inaturalist.org/observations/183332621 |
| _Ninox boobook_ | owls | Australian Boobook | CC-BY-NC | angebake | https://www.inaturalist.org/observations/325161984 |
| _Ninox boobook_ | owls | Australian Boobook | CC-BY-NC | Mark | https://www.inaturalist.org/observations/140872790 |
| _Ninox strenua_ | owls | Powerful Owl | CC-BY | Ian Rainbow | https://www.inaturalist.org/observations/109072596 |
| _Ninox strenua_ | owls | Powerful Owl | CC-BY-NC | rjennion | https://www.inaturalist.org/observations/208248224 |
| _Ninox strenua_ | owls | Powerful Owl | CC-BY | Ian Rainbow | https://www.inaturalist.org/observations/111079824 |
| _Otus scops_ | owls | Eurasian Scops-Owl | CC-BY-NC | marionlaremoise | https://www.inaturalist.org/observations/88440780 |
| _Otus scops_ | owls | Eurasian Scops-Owl | CC-BY-NC | Jakob Fahr | https://www.inaturalist.org/observations/154629691 |
| _Otus scops_ | owls | Eurasian Scops-Owl | CC-BY-NC | E. Raven Teva | https://www.inaturalist.org/observations/107522834 |
| _Strix aluco_ | owls | Tawny Owl | CC-BY | Patrick Hacker | https://www.inaturalist.org/observations/118566351 |
| _Strix aluco_ | owls | Tawny Owl | CC-BY-NC | natalya_khristolybova72 | https://www.inaturalist.org/observations/340615877 |
| _Strix aluco_ | owls | Tawny Owl | CC-BY-NC | Kajks | https://www.inaturalist.org/observations/312543971 |
| _Strix varia_ | owls | Barred Owl | CC-BY-NC | kitemongoose | https://www.inaturalist.org/observations/95440844 |
| _Strix varia_ | owls | Barred Owl | CC-BY-NC | kitemongoose | https://www.inaturalist.org/observations/134671618 |
| _Strix varia_ | owls | Barred Owl | CC-BY-NC | kitemongoose | https://www.inaturalist.org/observations/95778152 |
| _Callosciurus erythraeus_ | squirrels | Pallas' Squirrel | CC0 | Davide | https://www.inaturalist.org/observations/307355906 |
| _Callosciurus erythraeus_ | squirrels | Pallas' Squirrel | CC-BY-SA | portioid | https://www.inaturalist.org/observations/10506667 |
| _Callosciurus erythraeus_ | squirrels | Pallas' Squirrel | CC-BY-NC | lava_chen | https://www.inaturalist.org/observations/195080398 |
| _Callosciurus finlaysonii_ | squirrels | Finlayson's Squirrel | CC-BY-NC | luluchouette | https://www.inaturalist.org/observations/86840663 |
| _Callosciurus finlaysonii_ | squirrels | Finlayson's Squirrel | CC-BY-NC | Patrick James | https://www.inaturalist.org/observations/277309987 |
| _Callosciurus finlaysonii_ | squirrels | Finlayson's Squirrel | CC-BY-NC | Patrick James | https://www.inaturalist.org/observations/277309987 |
| _Funambulus palmarum_ | squirrels | Three-striped Palm Squirrel | CC-BY-NC | dogsarethecoolest | https://www.inaturalist.org/observations/195639229 |
| _Funambulus palmarum_ | squirrels | Three-striped Palm Squirrel | CC-BY-NC | dogsarethecoolest | https://www.inaturalist.org/observations/195639229 |
| _Funambulus palmarum_ | squirrels | Three-striped Palm Squirrel | CC-BY-NC | einadia | https://www.inaturalist.org/observations/188459018 |
| _Marmota marmota_ | squirrels | Alpine Marmot | CC-BY-NC | jansson | https://www.inaturalist.org/observations/222704433 |
| _Marmota marmota_ | squirrels | Alpine Marmot | CC-BY-NC | roby | https://www.inaturalist.org/observations/179965718 |
| _Marmota marmota_ | squirrels | Alpine Marmot | CC-BY-NC | roby | https://www.inaturalist.org/observations/379697882 |
| _Marmota monax_ | squirrels | Groundhog | CC-BY-NC | Michael H. King | https://www.inaturalist.org/observations/165803246 |
| _Marmota monax_ | squirrels | Groundhog | CC-BY-NC | Michael H. King | https://www.inaturalist.org/observations/165803246 |
| _Marmota monax_ | squirrels | Groundhog | CC-BY-NC | Erin O'Connor | https://www.inaturalist.org/observations/356840607 |
| _Otospermophilus beecheyi_ | squirrels | California Ground Squirrel | CC-BY-NC | Linda Pardy | https://www.inaturalist.org/observations/262432524 |
| _Otospermophilus beecheyi_ | squirrels | California Ground Squirrel | CC-BY-NC | Chalon Boesel | https://www.inaturalist.org/observations/150789369 |
| _Otospermophilus beecheyi_ | squirrels | California Ground Squirrel | CC-BY-NC | ekm18 | https://www.inaturalist.org/observations/113895262 |
| _Sciurus carolinensis_ | squirrels | Eastern Gray Squirrel | CC-BY-NC | joe dziewa | https://www.inaturalist.org/observations/190011349 |
| _Sciurus carolinensis_ | squirrels | Eastern Gray Squirrel | CC-BY-NC | little_blue_heron | https://www.inaturalist.org/observations/277770838 |
| _Sciurus carolinensis_ | squirrels | Eastern Gray Squirrel | CC-BY-NC | sea-kangaroo | https://www.inaturalist.org/observations/18359173 |
| _Sciurus carolinensis_ | squirrels | Eastern Gray Squirrel | CC-BY-NC | joe dziewa | https://www.inaturalist.org/observations/190011349 |
| _Sciurus carolinensis_ | squirrels | Eastern Gray Squirrel | CC-BY-NC | little_blue_heron | https://www.inaturalist.org/observations/277770838 |
| _Sciurus carolinensis_ | squirrels | Eastern Gray Squirrel | CC-BY-NC | sea-kangaroo | https://www.inaturalist.org/observations/18359173 |
| _Sciurus griseus_ | squirrels | Western Gray Squirrel | CC-BY-NC | dunnahoo | https://www.inaturalist.org/observations/249090560 |
| _Sciurus griseus_ | squirrels | Western Gray Squirrel | CC-BY-NC | Camila VR | https://www.inaturalist.org/observations/262001842 |
| _Sciurus griseus_ | squirrels | Western Gray Squirrel | CC-BY-NC | Jeff Ward | https://www.inaturalist.org/observations/142879805 |
| _Sciurus niger_ | squirrels | Eastern Fox Squirrel | CC-BY-NC | Lauren | https://www.inaturalist.org/observations/344934247 |
| _Sciurus niger_ | squirrels | Eastern Fox Squirrel | CC-BY-NC | hammhead292 | https://www.inaturalist.org/observations/185295683 |
| _Sciurus niger_ | squirrels | Eastern Fox Squirrel | CC0 | Ian | https://www.inaturalist.org/observations/158940636 |
| _Tamias striatus_ | squirrels | Eastern Chipmunk | CC-BY-NC | Daniel Onea | https://www.inaturalist.org/observations/15339961 |
| _Tamias striatus_ | squirrels | Eastern Chipmunk | CC-BY-NC | Summit Metro Parks | https://www.inaturalist.org/observations/274672356 |
| _Tamias striatus_ | squirrels | Eastern Chipmunk | CC-BY-NC | Ethan | https://www.inaturalist.org/observations/198958115 |
| _Colaptes pitius_ | woodpeckers | Chilean Flicker | CC-BY | Nicolas Olejnik | https://www.inaturalist.org/observations/187909799 |
| _Colaptes pitius_ | woodpeckers | Chilean Flicker | CC-BY-NC | Boyka | https://www.inaturalist.org/observations/145255694 |
| _Colaptes pitius_ | woodpeckers | Chilean Flicker | CC-BY-NC | Diego Almendras | https://www.inaturalist.org/observations/122427150 |
| _Dendrocopos leucotos_ | woodpeckers | White-backed Woodpecker | CC-BY-NC | Svetlana Akulova | https://www.inaturalist.org/observations/264948719 |
| _Dendrocopos leucotos_ | woodpeckers | White-backed Woodpecker | CC-BY-NC | Svetlana Akulova | https://www.inaturalist.org/observations/264948719 |
| _Dendrocopos leucotos_ | woodpeckers | White-backed Woodpecker | CC-BY-NC | Svetlana Akulova | https://www.inaturalist.org/observations/264948719 |
| _Dryobates minor_ | woodpeckers | Lesser Spotted Woodpecker | CC-BY-NC | practicepeas | https://www.inaturalist.org/observations/362003077 |
| _Dryobates minor_ | woodpeckers | Lesser Spotted Woodpecker | CC-BY-NC | practicepeas | https://www.inaturalist.org/observations/362003077 |
| _Dryobates minor_ | woodpeckers | Lesser Spotted Woodpecker | CC-BY-NC | Herbert Stadelmann | https://www.inaturalist.org/observations/335807590 |
| _Dryobates nuttallii_ | woodpeckers | Nuttall's Woodpecker | CC0 | Sarah Angulo | https://www.inaturalist.org/observations/78578654 |
| _Dryobates nuttallii_ | woodpeckers | Nuttall's Woodpecker | CC-BY-NC | Susan Levinson | https://www.inaturalist.org/observations/245967997 |
| _Dryobates nuttallii_ | woodpeckers | Nuttall's Woodpecker | CC-BY-NC | Phil Calvert | https://www.inaturalist.org/observations/235944620 |
| _Dryobates scalaris_ | woodpeckers | Ladder-backed Woodpecker | CC-BY-NC | Kelly Tolentino | https://www.inaturalist.org/observations/269066765 |
| _Dryobates scalaris_ | woodpeckers | Ladder-backed Woodpecker | CC-BY-NC | Kelly Tolentino | https://www.inaturalist.org/observations/269066765 |
| _Dryobates scalaris_ | woodpeckers | Ladder-backed Woodpecker | CC-BY-NC | Daniel S. Cooper | https://www.inaturalist.org/observations/339889495 |
| _Dryocopus martius_ | woodpeckers | Black Woodpecker | CC-BY | Daniel Castanhal García | https://www.inaturalist.org/observations/306074015 |
| _Dryocopus martius_ | woodpeckers | Black Woodpecker | CC-BY-NC | Simon Eisele | https://www.inaturalist.org/observations/46076152 |
| _Dryocopus martius_ | woodpeckers | Black Woodpecker | CC-BY | Marianna Boi | https://www.inaturalist.org/observations/46502702 |
| _Dryocopus pileatus_ | woodpeckers | Pileated Woodpecker | CC-BY-NC | Brenna Farrell | https://www.inaturalist.org/observations/73362354 |
| _Dryocopus pileatus_ | woodpeckers | Pileated Woodpecker | CC-BY-NC | Mélodie | https://www.inaturalist.org/observations/216050823 |
| _Dryocopus pileatus_ | woodpeckers | Pileated Woodpecker | CC0 | Chase Harris | https://www.inaturalist.org/observations/350338979 |
| _Jynx torquilla_ | woodpeckers | Eurasian Wryneck | CC-BY-NC | jansson | https://www.inaturalist.org/observations/113966440 |
| _Jynx torquilla_ | woodpeckers | Eurasian Wryneck | CC-BY-NC | tatianakirova | https://www.inaturalist.org/observations/340014891 |
| _Jynx torquilla_ | woodpeckers | Eurasian Wryneck | CC-BY-NC | Quirin | https://www.inaturalist.org/observations/218986221 |
| _Leuconotopicus villosus_ | woodpeckers | Hairy Woodpecker | CC-BY-NC | Cynthia Brossard | https://www.inaturalist.org/observations/36924478 |
| _Leuconotopicus villosus_ | woodpeckers | Hairy Woodpecker | CC-BY-NC | jmwilkerson | https://www.inaturalist.org/observations/100026809 |
| _Leuconotopicus villosus_ | woodpeckers | Hairy Woodpecker | CC-BY-NC | little_blue_heron | https://www.inaturalist.org/observations/191490178 |
| _Melanerpes candidus_ | woodpeckers | White Woodpecker | CC-BY | Nico Fernandez-Sauleda | https://www.inaturalist.org/observations/190992420 |
| _Melanerpes candidus_ | woodpeckers | White Woodpecker | CC-BY-NC | Claudio Martins de Souza | https://www.inaturalist.org/observations/92188871 |
| _Melanerpes candidus_ | woodpeckers | White Woodpecker | CC-BY-NC | Hugo | https://www.inaturalist.org/observations/318380081 |
| _Picus canus_ | woodpeckers | Grey-headed Woodpecker | CC-BY-NC | Michele Chiacchio | https://www.inaturalist.org/observations/50080539 |
| _Picus canus_ | woodpeckers | Grey-headed Woodpecker | CC-BY-NC | Peter Holub | https://www.inaturalist.org/observations/129245780 |
| _Picus canus_ | woodpeckers | Grey-headed Woodpecker | CC-BY-NC | Любовь | https://www.inaturalist.org/observations/167013221 |
| _Sphyrapicus varius_ | woodpeckers | Yellow-bellied Sapsucker | CC-BY | Jamie VanBuskirk | https://www.inaturalist.org/observations/211163944 |
| _Sphyrapicus varius_ | woodpeckers | Yellow-bellied Sapsucker | CC-BY-NC | mixxiechick | https://www.inaturalist.org/observations/85531183 |
| _Sphyrapicus varius_ | woodpeckers | Yellow-bellied Sapsucker | CC-BY-NC | Kristen M | https://www.inaturalist.org/observations/207840650 |

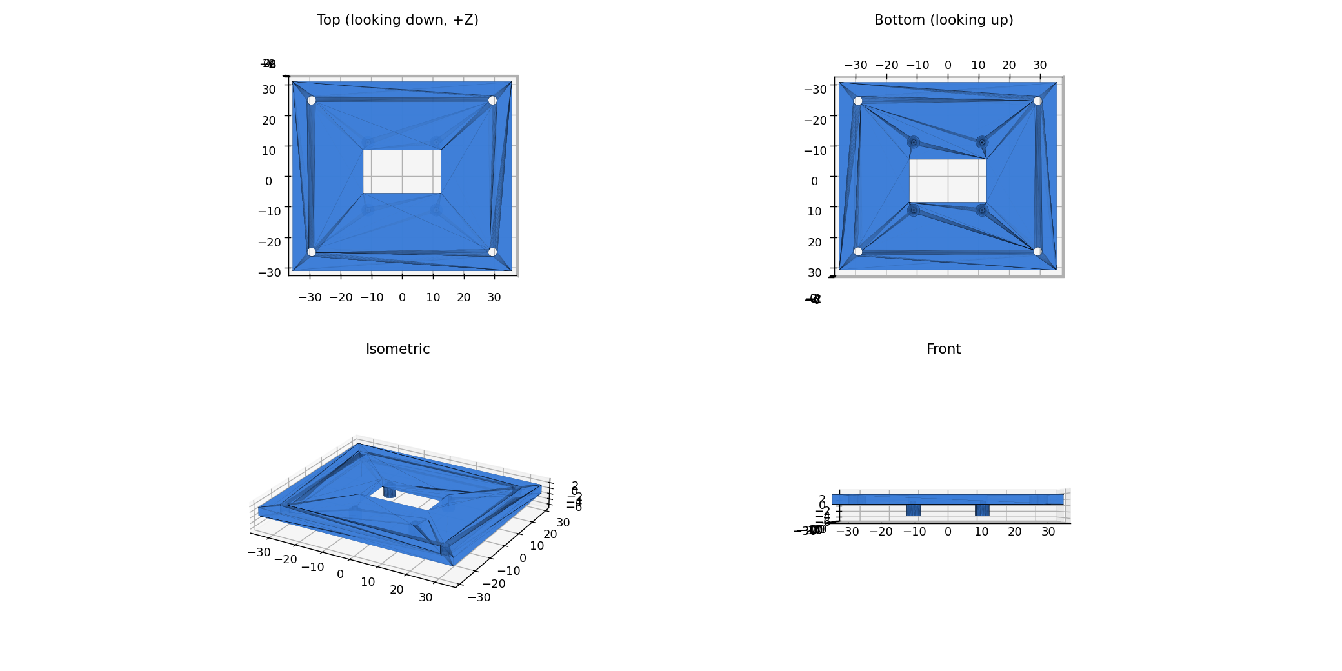
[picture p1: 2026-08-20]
docs/hardware/oled_bracket/oled_bracket_preview.png

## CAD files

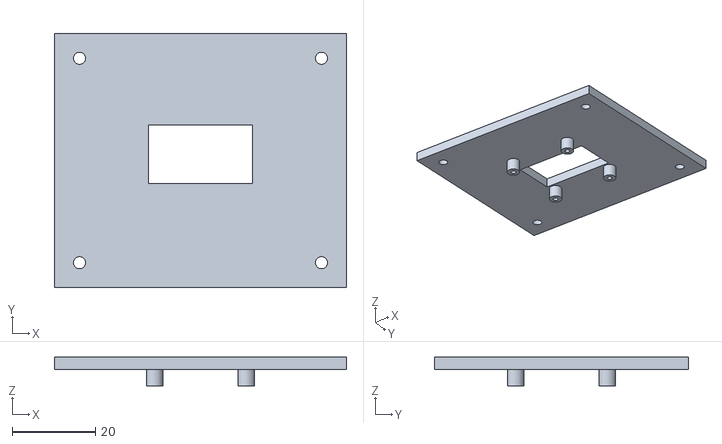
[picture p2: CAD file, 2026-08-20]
docs/hardware/oled_bracket/oled_bracket.stl
70.0 x 61.0 x 6.90

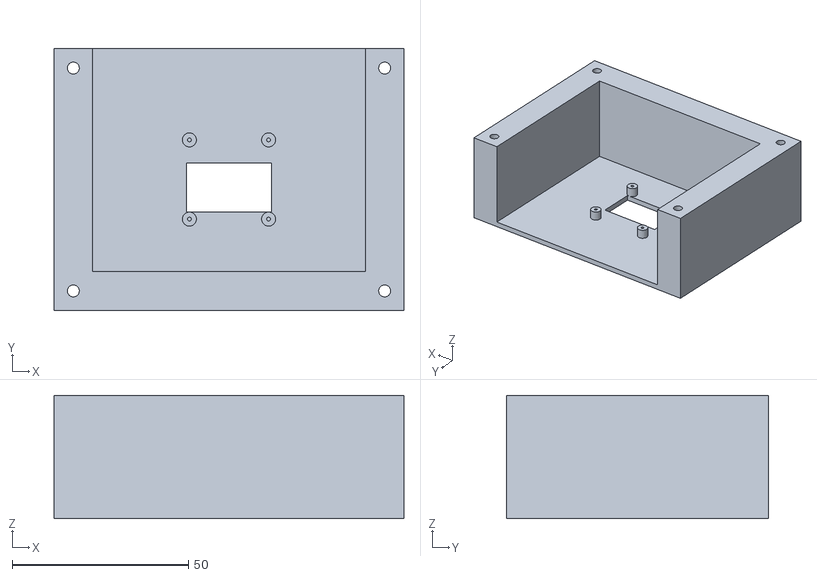
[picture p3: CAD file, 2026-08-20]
docs/hardware/enclosure_design/X306_TopPart_PrintOrientation.stl
99.4 x 74.3 x 35.0

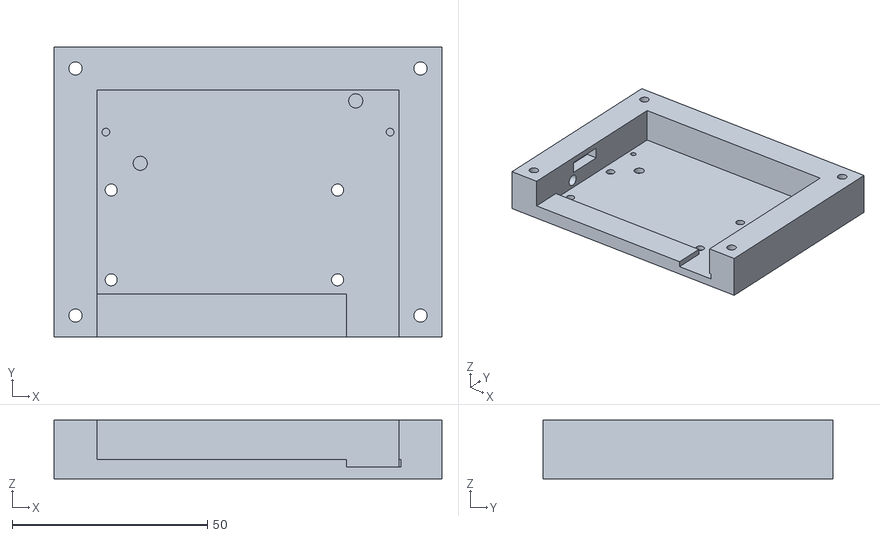
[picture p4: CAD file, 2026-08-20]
docs/hardware/enclosure_design/X306_Panel.stl
99.4 x 74.3 x 15.0

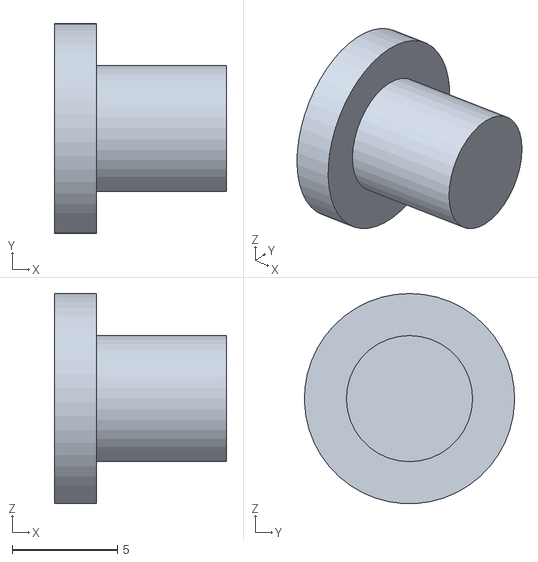
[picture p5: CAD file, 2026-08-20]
docs/hardware/enclosure_design/PSW_Button_Extender.stl
8.20 x 9.99 x 9.99

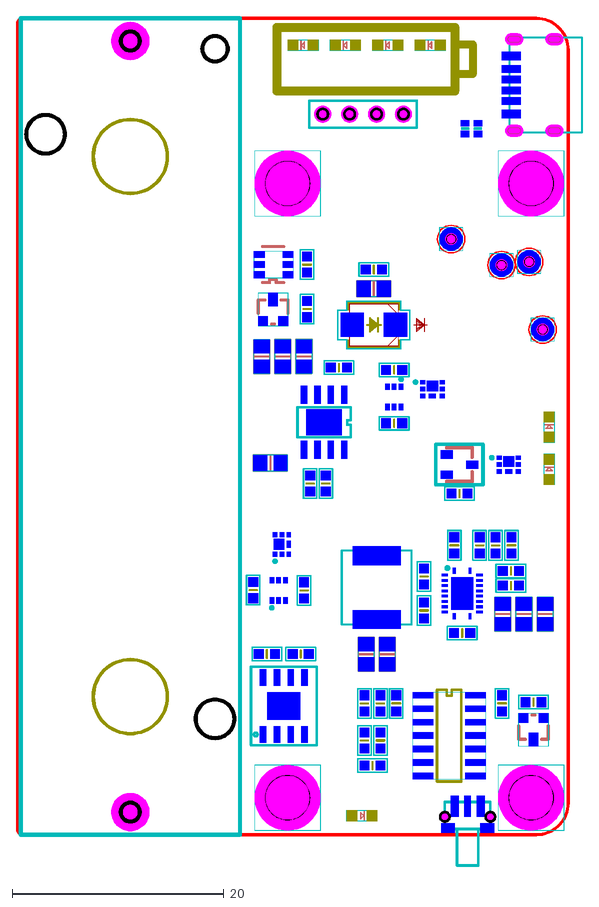
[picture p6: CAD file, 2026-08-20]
docs/hardware/enclosure_design/X306-pcb-v1.3(1).dxf
53.5 x 80.3

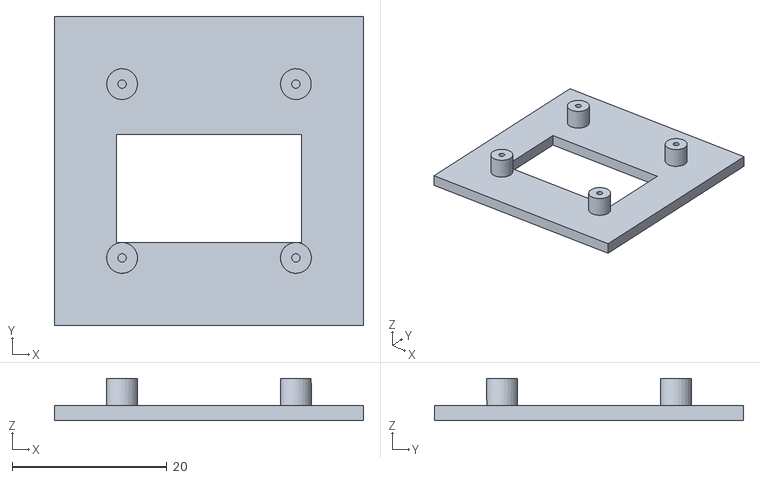
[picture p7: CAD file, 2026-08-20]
docs/hardware/enclosure_design/X306_OLED_ScrewTest_Sample.stl
40.0 x 40.0 x 5.50

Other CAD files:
docs/hardware/enclosure_design/X306_TopPart.stl
docs/hardware/enclosure_design/X306_Panel.f3d

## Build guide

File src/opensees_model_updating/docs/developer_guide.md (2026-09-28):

# Developer Guide

This guide is for developers picking up the codebase. It covers environment setup,
project layout, how the pieces connect, and how to extend the package.

---

## Repository layout

```
opensees-model-updating/
├── docs/
│   ├── pipeline.md             # Data flow + integration points (start here)
│   └── developer_guide.md     # This file
├── input/                      # Runtime input data (committed)
│   ├── experimental_modal_data.json
│   └── sine_*Hz_accel.txt
├── output/                     # Runtime outputs (gitignored, created at run time)
│   └── .gitkeep
├── src/                        # The Python package (maps to opensees_model_updating)
│   ├── __init__.py
│   ├── __main__.py
│   ├── analysis/
│   │   ├── gravity.py          — static gravity + load-const reset
│   │   ├── modal.py            — eigenvalue extraction, mode-shape plots
│   │   └── transient.py        — Newmark integration, real-time animation
│   ├── calibration/
│   │   └── calibrator.py       — scipy TRF optimizer, objective function
│   ├── cli/
│   │   └── main.py             — main() entry point (post-GUI analysis flow)
│   ├── domain/
│   │   └── enums.py            — ColumnOrientation, AnalysisType, MassCalibrationScope
│   ├── gui/
│   │   ├── main_window.py      — launch_input_window() full Tkinter GUI
│   │   └── widgets/
│   │       └── canvas_widget.py — plan-view + 3D sketch helpers
│   ├── io/
│   │   └── loaders.py          — JSON/text I/O, experimental data loading/validation
│   ├── model/
│   │   └── builder.py          — OpenSees model construction (nodes, elements, mass)
│   ├── reporting/
│   │   └── calibration_report.py — report dicts, text, 4-panel figure
│   ├── utils/
│   │   ├── formatters.py       — rounding, layout-to-text helpers
│   │   └── math_utils.py       — mode normalization, sign alignment, percent error
│   └── visualization/
│       └── __init__.py         — re-exports from analysis modules
├── environment.yml             # Conda environment spec
├── pyproject.toml              # Build config + entry points
├── README.md
└── run.py                      # One-file launcher
```

---

## Setup

```bash
# 1. Create the environment from the spec
conda env create -f environment.yml
conda activate opensees

# 2. Launch
python run.py
```

---

## Entry points

| Command | Resolves to |
|---|---|
| `python run.py` | `src/cli/main.py → main()` |

---

## Call graph (high level)

```
main()                          cli/main.py
  └── launch_input_window()     gui/main_window.py
        ├── [Calibrate button]
        │     ├── prepare_experimental_modal_data()   calibration/calibrator.py
        │     ├── extract_modal_results()             analysis/modal.py
        │     ├── run_calibration()                   calibration/calibrator.py
        │     ├── make_modal_comparison_report()      reporting/calibration_report.py
        │     └── run_transient_analysis_collect_data()  analysis/transient.py
        └── [Run Analysis button]
              ├── extract_modal_results()
              ├── plot_modal_results_calibrated_only()
              └── run_transient_analysis_with_visualization()

extract_modal_results()         analysis/modal.py
  ├── build_model()             model/builder.py
  ├── run_gravity_analysis()    analysis/gravity.py
  └── run_eigen_with_fallback()
```

---

## Key data structures

### `params` dict

The central configuration object built by `collect_gui_inputs()` in `gui/main_window.py`.
All downstream functions accept it. Keys:

| Key | Type | Description |
|---|---|---|
| `nStory` | `int` | Number of stories |
| `Lx`, `Ly` | `float` | Plan dimensions (m) |
| `story_heights` | `list[float]` | Height of each story (m), length = nStory |
| `floor_masses` | `list[float]` | Self-weight mass per floor (kg), length = nStory |
| `t_column`, `b_column` | `float` | Column cross-section dimensions (m) |
| `b_beam`, `h_beam` | `float` | Beam cross-section dimensions (m) |
| `E` | `float` | Elastic modulus (Pa) |
| `nu` | `float` | Poisson ratio |
| `numModes` | `int` | Number of modes to extract |
| `zeta` | `float` | Rayleigh damping ratio |
| `gmFile` | `str` | Path to ground-motion record |
| `dtGM` | `float` | Time step of ground-motion record (s) |
| `gmFactor` | `float` | Scale factor applied to record |
| `story_column_layout` | `dict[int, list[int]]` | `{story: [col_ids present]}` |
| `column_orientation_layout` | `dict[int, dict[int, str]]` | `{story: {col_id: "weak"/"strong"}}` |
| `additional_masses` | `dict[int, list[float]]` | `{story: [center, C1, C2, C3, C4]}` in kg |
| `enable_calibration` | `bool` | Whether to run calibration |
| `nCalibModes` | `int` | Modes used in calibration objective |
| `mass_calibration_scope` | `str` | `"self_weight_only"` or `"total_mass"` |
| `w_freq`, `w_mode` | `float` | Objective function weights |
| `E_scale_lb/ub`, `m_scale_lb/ub` | `float` | Optimizer bounds |

### `modal_data` dict

Returned by `extract_modal_results()`. Keys:

| Key | Description |
|---|---|
| `freqs` | `np.array` — natural frequencies (Hz) |
| `periods` | `np.array` — periods (s) |
| `mode_shapes_ux_master` | `list[np.array]` — UX mode shapes at master nodes |
| `ctx` | Model context dict from `build_model()` |

### `exp_data` dict

Returned by `prepare_experimental_modal_data()`. Keys:

| Key | Description |
|---|---|
| `frequencies_hz` | `np.array` — experimental frequencies |
| `mode_shapes_ux` | `list[np.array]` — normalized experimental mode shapes (or `None`) |
| `mode_shapes_available` | `bool` |
| `raw_data` | Original parsed JSON |

---

## Adding a new analysis type

1. Add a value to `domain/enums.py → AnalysisType`.
2. Create `src/analysis/<new_type>.py`.
3. Export from `src/analysis/__init__.py`.
4. Wire a button or parameter in `src/gui/main_window.py`.

## Adding a new calibration parameter

1. Add the bound entries to the GUI in `gui/main_window.py → Tab 3`.
2. Extend `collect_gui_inputs()` to read and validate the new field.
3. Extend `apply_calibration_vector()` in `calibration/calibrator.py` to apply it.
4. Update `modal_residuals()` if it changes the objective.

---

## Running tests

```bash
conda activate opensees
pytest src/tests/ -v
```

Tests live in `src/tests/`.

---

## Linting and formatting

```bash
black src/
ruff check src/
```

---

## Legacy reference

`docs/legacy_monolith.py` is the original single-file implementation (`DigitalTwin_V8.py`)
from which this package was refactored. It is kept **for reference only** and must not
be run or imported.

Useful for tracing how a specific behaviour was originally coded:

| Original function | Now lives in |
|---|---|
| `build_model()` | `src/model/builder.py` |
| `run_gravity_analysis()` | `src/analysis/gravity.py` |
| `run_eigen_with_fallback()` | `src/analysis/modal.py` |
| `run_transient_analysis_*()` | `src/analysis/transient.py` |
| `run_calibration()` / `modal_residuals()` | `src/calibration/calibrator.py` |
| `launch_input_window()` | `src/gui/main_window.py` |
| `make_modal_comparison_report()` | `src/reporting/calibration_report.py` |
| `load_experimental_modal_data()` | `src/io/loaders.py` |
| `r3()`, `sci3()`, `deep_round()` | `src/utils/formatters.py` |
| `normalize_mode_maxabs()` | `src/utils/math_utils.py` |

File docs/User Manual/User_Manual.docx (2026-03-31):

# SensePi GUI Manual

Version 1, 15.12.2025

Introduction:

This manual is related to the setup shown in Figure 1, which consists of a Raspberry Pi Zero 2 WH acting as the main computer that runs the logger/software and communicates with the sensor over I2C while streaming/recording data over the network, powered through a Geekworm X306 V1.3 ultra-thin UPS shield supplied by USB-C and backed up by a single rechargeable 3.7 V battery cell; a Freenove GPIO breakout block HAT is used to provide clean, reliable wiring access to the Pi’s 40-pin GPIO, and the motion data is measured by 3 MPU-6050 (GY-521) IMU module that provides 3-axis acceleration and 3-axis gyroscope measurements via I2C.

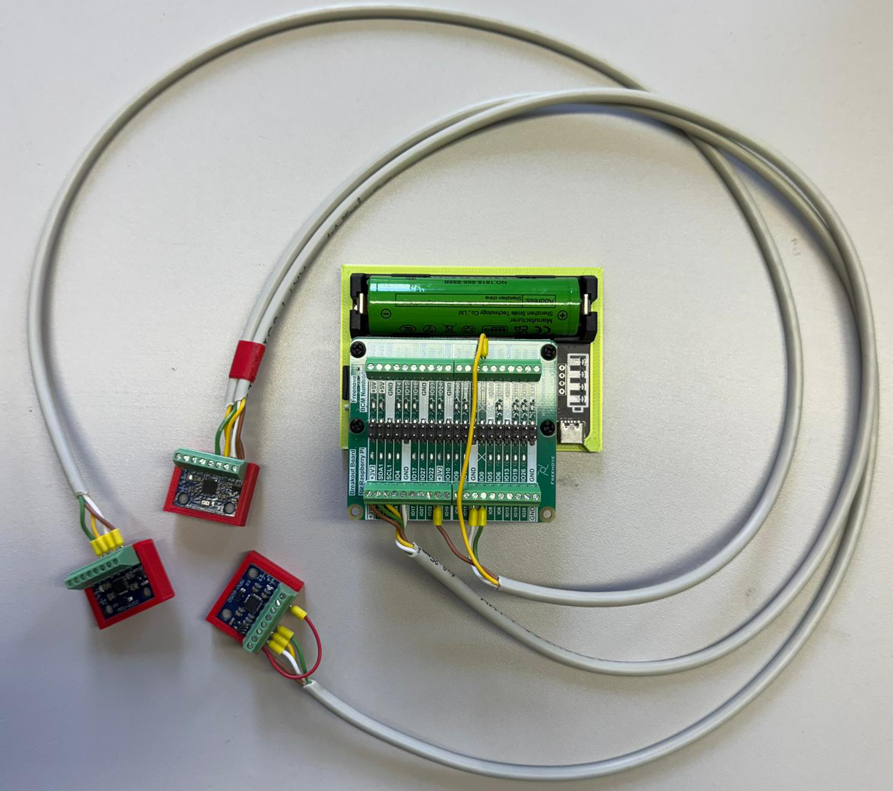
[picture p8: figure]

Figure 1: SensePi setup.

This manual shows how to operate the SensePi for data acquisition. For installation, please refer to the readme.md file in the repository.

1. Raspberry Pi credentials:

user: “verwalter”

password: “66442200”

Network settings: the Raspberry Pi needs to connect to a a wirless adapater with the name ‘MissionControl’ and with a password ”!6644200”. The pi’s has fixed ip address (e.g. 192.168.0.103), and the router should be set up to be in the same range.

2. Run main.py :

Run the main.py file in your IDE or in terminal with the command (python main.py).

SensePi’s main window, as shown in Figure 2, is a tabbed interface:

- Live Signals – starts/stops streaming and shows time‑domain plots
- Spectrum – FFT/spectrum view
- Settings – where you set up Raspberry Pi hosts and sensor defaults

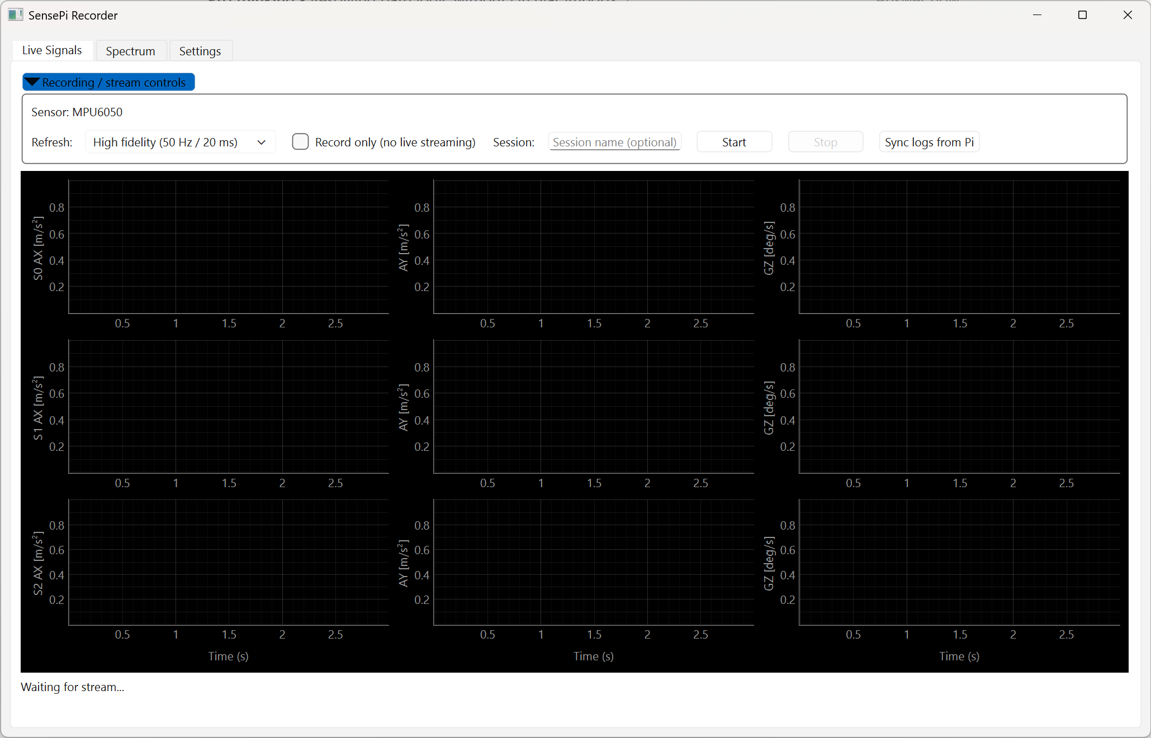
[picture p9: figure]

Figure 2: Main window tabs.

3. Make sure the Raspberry Pi is running

Before configuring sensors, confirm the Pi is powered and reachable.

### 3.1 Quick physical / network checks (outside the GUI)

1. Power: Pi is powered (power LED on).
2. Network: Pi is on the same network as the PC (Ethernet or Wi‑Fi).
3. SSH enabled (required by SensePi): you can SSH into the Pi from another terminal if needed.

Note: The IP address of the SensePi is 10X based on the label at the back of the case.

### 3.2 Confirm the Pi is reachable using the GUI

1. Open the Settings tab.

Select your Pi in the Raspberry Pi hosts list (or add it if it’s not listed).

Click save hosts.yaml and save sensors.yaml. Then press on Sync Pi defaults (pi_config.yaml)

If the sync succeeds, the Pi is reachable over SSH and SensePi can access the expected remote folders.

#### If the sync fails

Most failures mean one of these is wrong:

- Host/IP, username, or password
- The remote paths (scripts folder / data folder) don’t exist yet on the Pi

Fix the host fields in Settings and try again.

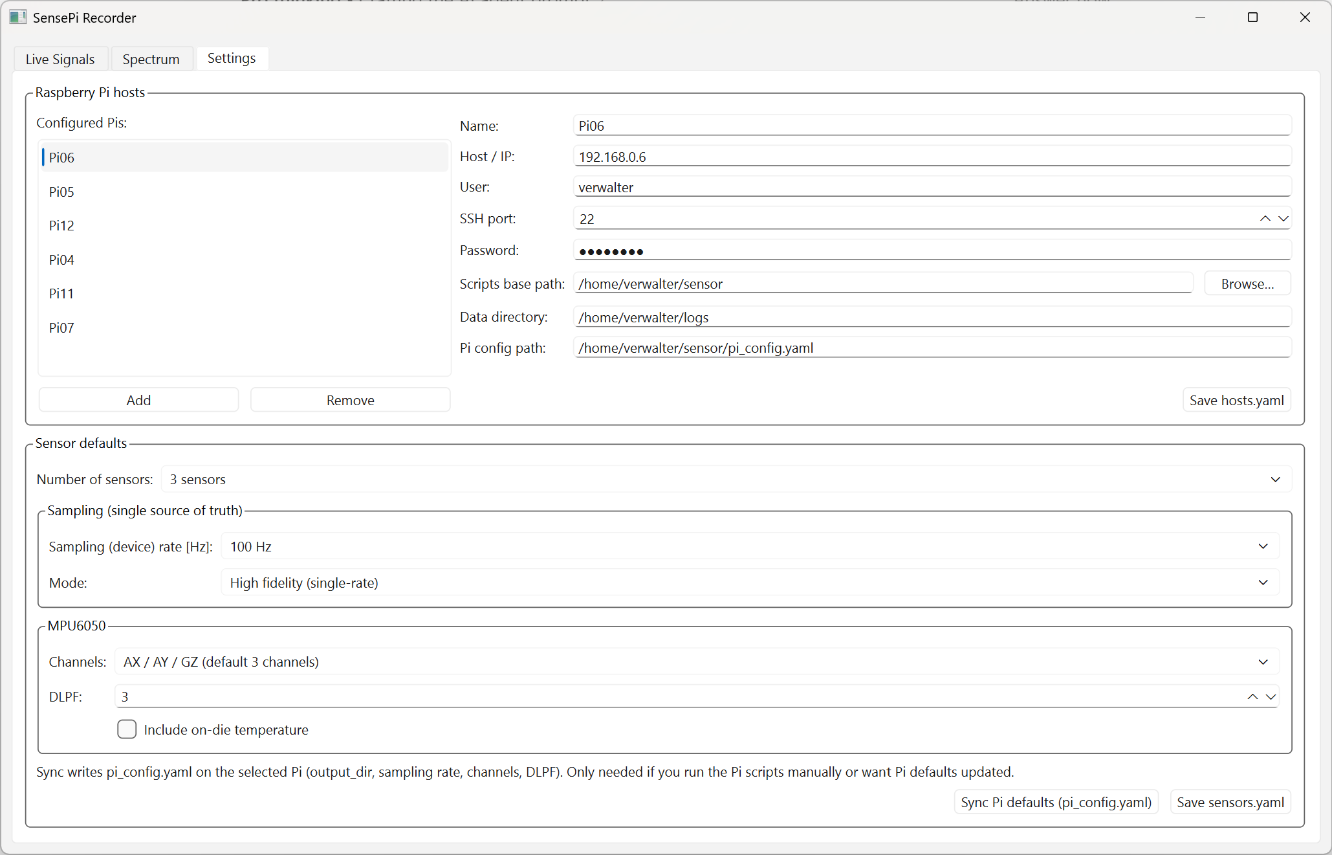
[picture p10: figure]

Figure 3: Settings tab: “Sync Pi defaults (pi_config.yaml)” button.

## 4. Settings tab: select a host (or add your Pi)

The Settings tab contains a full host editor: a list of hosts on the left, and editable fields on the right.

### 4.1 Select an existing Pi host

Go to Settings.

In Raspberry Pi hosts, click your Pi’s name.

Confirm the fields are correct (IP/hostname, user, port, password, paths).

### 4.2 Add a new Pi host (if your Pi is not listed)

In Settings → Raspberry Pi hosts, click Add host.

Fill in the host fields (typical examples):

Name: a friendly name, e.g. `LabPi`

Host / IP: e.g. `192.168.0.105`

User: verwalter

SSH port: 22

Password: 66442200

Scripts base path: where the SensePi scripts live on the Pi (e.g. /home/verwalter/sensor)

Data directory: where recordings/logs should be saved (e.g. /home/verwalter/logs)

Pi config path: path to `pi_config.yaml` on the Pi (e.g. /home/verwalter/sensor/pi_config.yaml)

Click Save hosts.yaml.

## 5. Settings tab: choose sensor IDs (MPU6050)

SensePi’s default logger supports up to 3 MPU6050 sensors and uses numeric sensor IDs.

### 5.1 Choose how many sensors you have

4. In Settings, find Sensor defaults (and the MPU6050 group).
5. Set Number of sensors to:
- `1 sensor` (uses sensor ID 0)
- `2 sensors` (uses sensor IDs 0-1)
- `3 sensors` (uses sensor IDs 0–2)
6. Click Save sensors.yaml.

### 5.2 Choose channels (3‑axis vs 6‑axis)

In the same MPU6050 area, set Channels to match what you want to stream/record:

- `AX / AY / GZ (default 3 channels)`
- `AX / AY / AZ (acc only)`
- `GX / GY / GZ (gyro only)`
- `AX / AY / AZ / GX / GY / GZ (6-axis)`

5.3 DLPF

set the low pass filter, as per the datasheet of the sensor. Hover on the box to see what are the filtering frequncies for both angular velocity and accelerlation for every filter level.

### 5.4 Push the Settings to the Pi

After updating hosts or sensor defaults:

Select the correct Pi host in Settings.

Click Sync Pi defaults (pi_config.yaml).

This pushes the sensor defaults into the Pi’s `pi_config.yaml` and is also the easiest “one-click” way to confirm the Pi is reachable.

## 6. Live signals

Once your Pi host and sensor selection are correct:

Go to the Live Signals tab.

Enter an optional Session name.

Click Start to begin streaming.

For recording, Press only, which will start recording and save the file on the Pi. Then to get the recorded files, press on Sync logs from Pi and they will be copied to your local folder where you run the code from.

Note: The reason the recording is not accompanied with the live stream is that it allows you to record at higher sampling rate without much overruns (having the pi struggle to both send the data and record it locally).

Figure 4: Live Signals: Session / Start / Stop.

7. Spectrum

Shows the frequency spectrum using FFT per channel per sensor for a certain time window, as shown in Figure 5.

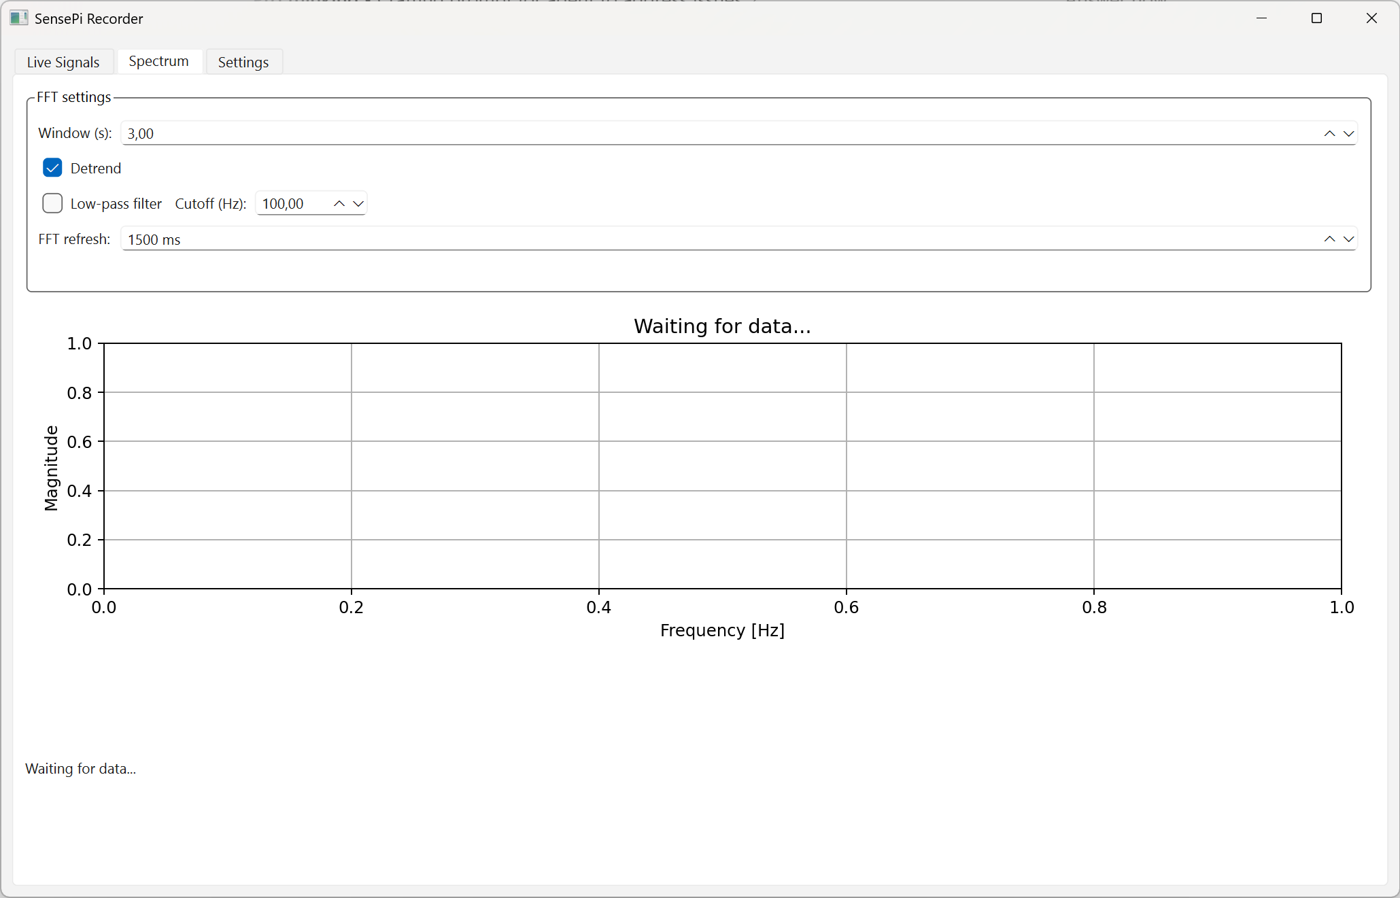
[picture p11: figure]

Figure 5: Spectrum tab.

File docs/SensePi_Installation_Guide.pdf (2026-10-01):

SensePi MPU · Installation and start-up guide | Page 1

ProTELC Science Camp

# SensePi MPU

### Installation and start-up guide for your laptop

SensePi is the app you use to measure how a model structure vibrates. It connects over Wi-Fi to a Raspberry Pi with four motion sensors attached, and lets you watch the signals live, record them, find the structure's natural frequencies and compare them with a computer model.

This guide takes you from the SensePi ZIP file to a running app, one step at a time. Type the commands exactly as shown. Where Windows and macOS differ, both are given: follow the one for your laptop.

Before you start, you need
- A laptop with Windows 10 or 11, or macOS.
- An internet connection for the installation (Steps 1 to 4).
- About 2 GB of free disk space and about 20 minutes, most of it waiting for downloads.
- The SensePi ZIP file from your instructor.
- For Step 6, later: your Raspberry Pi's IP address and password, from your instructor.

The steps

| Step | What you do
1 | Install Python 3.12 | Install the programming language SensePi is written in
2 | Unzip SensePi | Extract the ZIP file into a folder
3 | Open a terminal | Open a command window inside that folder
4 | Install SensePi's packages | Let Python download everything SensePi needs
5 | Start SensePi | Open the app
6 | Connect to your Raspberry Pi | Enter the Pi's details in the app
7 | Your first measurement | Watch and record the sensor signals

Steps 1 to 4 are done once. After that, starting SensePi takes two commands (see Starting SensePi again later).

STEP 1

## Install Python 3.12

Use Python 3.12, not the newest version

The big yellow Download Python button on python.org gives you the newest Python, which SensePi has not been tested with. Use the link below to get Python 3.12.10. If your laptop already has a different Python, that's fine: install 3.12 next to it.

Windows

1. Open this page in your web browser: https://www.python.org/downloads/release/python-31210/
2. Scroll down to Files and click Windows installer (64-bit).
3. Open the downloaded file. On the first screen, tick both boxes at the bottom: Use admin privileges when installing py.exe and Add python.exe to PATH. Then click Install Now.
4. When it finishes, click Disable path length limit if you see it (skip it if your laptop doesn't allow it), then click Close.
5. Check it worked: press the Start key, type PowerShell, open it, and type:

Windows (PowerShell)

py -3.12 --version

It should print Python 3.12.10. Then close PowerShell.

macOS

1. Open https://www.python.org/downloads/release/python-31210/ and click macOS 64-bit universal2 installer under Files.
2. Open the downloaded file and click through the installer.
3. Check it worked: open Terminal (press Cmd+Space, type Terminal, press Return) and type:

macOS (Terminal)

python3.12 --version

It should print Python 3.12.10.

STEP 2

## Unzip SensePi

Windows

1. Find the SensePi ZIP file, usually in your Downloads folder.
2. Right-click it and choose Extract All…. Click Browse…, choose Desktop, then click Select Folder and Extract.
3. Open the new folder on your Desktop. If it contains just one more folder, open that too. Stop when you see main.py and requirements.txt: this is your SensePi folder.

macOS

1. Double-click the ZIP file in Downloads. A folder appears next to it.

2. Drag that folder to your Desktop. Open it until you see main.py and requirements.txt: this is your SensePi folder.

Always extract the ZIP first

Windows lets you look inside a ZIP file without extracting it, but SensePi can't run from inside a ZIP. Also keep the folder somewhere simple like the Desktop: a folder buried many levels deep can make Step 4 fail with “The filename or extension is too long”.

Windows may hide file endings, so main.py can appear as just main.

STEP 3

## Open a terminal in the SensePi folder

A terminal is a window where you type commands. It must be opened inside the SensePi folder, so the commands find SensePi's files.

Windows

- Windows 11: in File Explorer, open your SensePi folder, right-click an empty space and choose Open in Terminal.
- Windows 10: in File Explorer, open your SensePi folder, click the address bar at the top, type powershell and press Enter.

macOS

- Open Terminal, type cd followed by a space, drag your SensePi folder from Finder into the Terminal window, and press Return.

Check that you're in the right place:

Windows

dir main.py

macOS

ls main.py

You should see main.py listed. If you get “cannot find” or “No such file”, the terminal is in the wrong folder: close it and repeat this step.

STEP 4

## Install SensePi's packages

Type these commands one at a time, pressing Enter after each. Wait for each to finish (the line with the blinking cursor comes back) before typing the next.

Windows (PowerShell)

py -3.12 -m venv .venv
.venv\Scripts\Activate.ps1
python -m pip install --upgrade pip pip install -r requirements.txt

macOS (Terminal)

python3.12 -m venv .venv
source .venv/bin/activate
python -m pip install --upgrade pip pip install -r requirements.txt

What these do:

- The first command makes a private Python environment for SensePi: a folder called .venv inside your SensePi folder. Nothing else on your laptop is changed.
- The second switches it on. From now on, your command line starts with (.venv).
- The last command downloads and installs everything SensePi needs (a few hundred MB). This takes several minutes. It is finished when you see Successfully installed … and the command line comes back.

Windows: “running scripts is disabled on this system”?

If the second command shows this red message, type the following once, answer Y, then type .venv\Scripts\Activate.ps1 again:
Set-ExecutionPolicy -Scope CurrentUser RemoteSigned
STEP 5

## Start SensePi

In the same terminal (it still shows (.venv)), type:

Windows and macOS

python main.py

The SensePi window opens. The first start can take up to a minute.

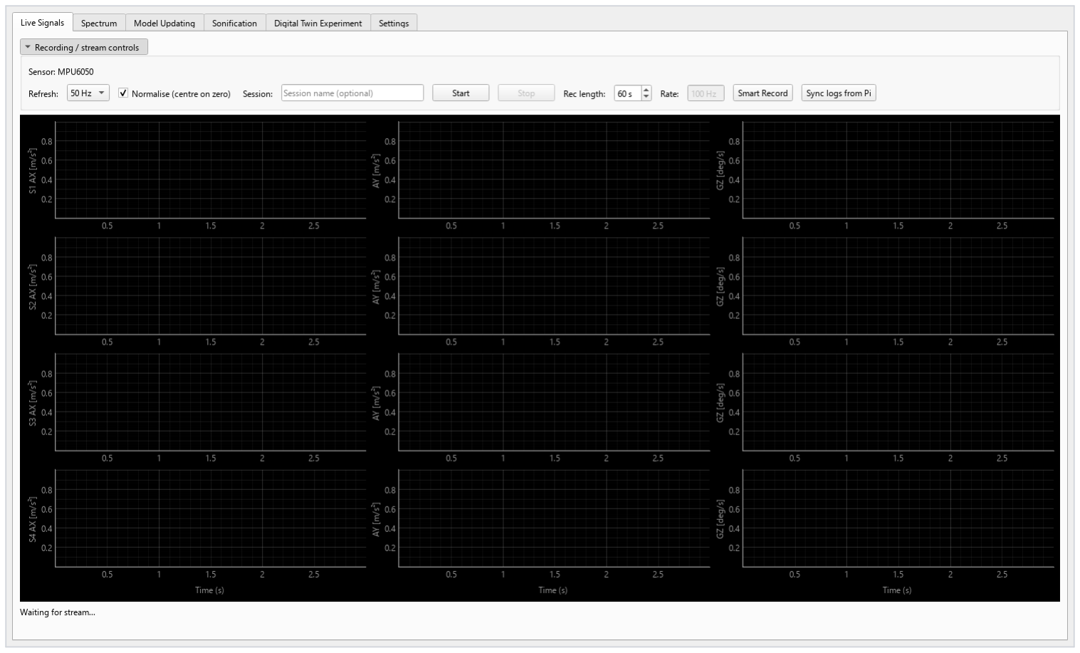
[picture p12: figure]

The SensePi window. The tabs along the top are Live Signals, Spectrum, Model Updating, Sonification, Digital Twin Experiment and Settings.

Keep the terminal open

SensePi runs from the terminal. Closing the terminal closes SensePi. Messages that appear in the terminal while SensePi runs are normal.

STEP 6

## Connect to your Raspberry Pi

Connect your laptop to the MissionControl Wi-Fi first

The Raspberry Pis can only be reached on the MissionControl Wi-Fi network. Laptops sometimes switch back to another saved network by themselves, so check this whenever SensePi can't connect.

Enter the Pi's details

1. Click the Settings tab.
2. Under Configured Pis, click ExamplePi.
3. Fill in the fields on the right as in the table below. Type the paths exactly as shown.
4. Click Save host config.

Field | What to type
Name | Any name you like, for example Pi-1
Host / IP | The Pi's IP address from your instructor (the Pi's small screen also shows it)
User | verwalter
SSH port | 22
Password | The password from your instructor
Scripts base path | /home/verwalter/sensor4
Data directory | /home/verwalter/logs
Pi config path | /home/verwalter/sensor4/pi_config.yaml

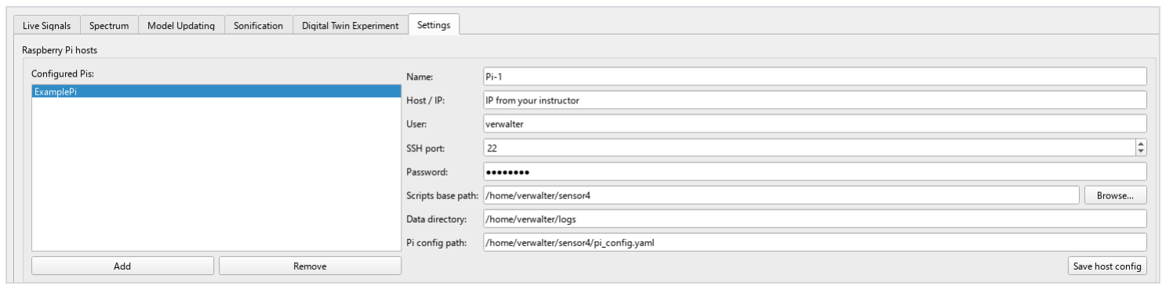
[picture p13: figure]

The Pi details filled in. Replace “IP from your instructor” with the real IP address.

Check the sensor settings

1. Further down, under Sensor defaults, check that Number of sensors is 4 sensors (it is by default).

Number of sensors: 4 sensors.

2. In the Sensor placement map, set each sensor's Floor and Location to where it is on your structure. Floor 0 is the base (the shaker). Every other tab uses this map, so ask your instructor if you're not sure.

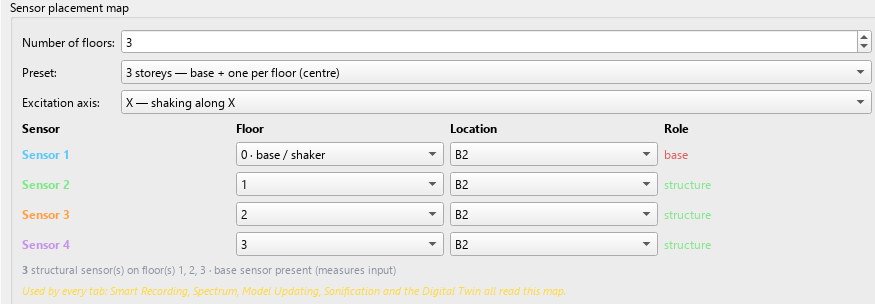
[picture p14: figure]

The sensor placement map, set here for a base sensor plus one sensor on each of three floors.

3. Click Save sensors.yaml.
4. Click Sync Pi defaults (pi_config.yaml) to send these settings to the Pi.

STEP 7

## Your first measurement

The recording controls at the top of the Live Signals tab.

1. Click the Live Signals tab, then Start.
2. Tap the structure gently and watch the signals move. There is one row of plots per sensor.
3. Click Stop when you're done.

To keep a measurement

1. Set Rec length to how many seconds you want to record. Record at least 30 seconds if you want to analyse it later in Model Updating.
2. Optionally type a Session name, for example team3_test1.
3. Click Smart Record. SensePi first checks the real sampling rate for a few seconds, then records for the length you chose and saves the file by itself.

## Starting SensePi again later

You only do Steps 1 to 4 once. Next time, open a terminal in your SensePi folder (Step 3) and type:

Windows (PowerShell)

.venv\Scripts\Activate.ps1
python main.py

macOS (Terminal)

source .venv/bin/activate
python main.py

Your Pi details and sensor map are remembered, so you don't have to enter them again.

## Where your data is saved

Everything SensePi saves goes into the output folder inside your SensePi folder:

Folder | What's inside
output/sensor_recordings | Your recorded measurements, one folder per recording
output/model | Computer-model files from Model Updating
output/digital_twin | Digital Twin experiment runs
output/sonification | Sound you captured

At the end of the camp

Copy the output folder somewhere safe before you delete the SensePi folder. To remove SensePi completely, just delete the SensePi folder.

## Troubleshooting

Problem | What to do
| Python 3.12 isn't installed, or Add python.exe to PATH wasn't ticked. Run the installer from Step 1 again, tick both boxes, then open a new terminal.

“running scripts is disabled on this system” (Windows)

Step 4 fails with “The filename or extension is too long” | | Your SensePi folder is too deep. Move it to your Desktop, delete the

py or python3.12 is “not recognized” / “command not found”, or typing python opens the Microsoft Store

Run Set-ExecutionPolicy -Scope CurrentUser RemoteSigned, answer Y, then run the activate command again.

.venv folder inside it, and do Step 4 again.

pip install says “No matching distribution found”

The environment was made with the wrong Python. Delete the .venv folder, check Step 1 (py -3.12 --version), and do Step 4 again.

SensePi says “matplotlib is not installed” or “No module named …”

The environment isn't switched on: your command line must start with (.venv). Run the activate command, then python main.py again. If it still fails, run pip install -r requirements.txt again.

SensePi can't connect to the Pi | Check that the laptop is on the MissionControl Wi-Fi, and check the IP address and password in Settings. Ask your instructor whether the Pi is switched on (its screen shows its IP address).
No signal, or a sensor is missing | In Settings, check Number of sensors is 4 sensors, then click Sync Pi defaults (pi_config.yaml) again. Check the sensor cables, then tell your instructor.
Plots are slow or jerky | Close other programs you don't need, or set Refresh lower in Live Signals.

## Quick reference

Keep this page handy. All commands are typed in a terminal opened in your SensePi folder.

| Windows (PowerShell) | macOS (Terminal)
Check Python | py -3.12 --version | python3.12 --version
Make the environment (once) | py -3.12 -m venv .venv | python3.12 -m venv .venv
Switch it on | .venv\Scripts\Activate.ps1 | source .venv/bin/activate
Install packages (once) | pip install -r requirements.txt | pip install -r requirements.txt
Start SensePi | python main.py | python main.py
Setting on the Pi | Value
Wi-Fi network | MissionControl
User | verwalter
SSH port | 22
Scripts base path | /home/verwalter/sensor4
Data directory | /home/verwalter/logs
Pi config path | /home/verwalter/sensor4/pi_config.yaml
IP address and password | From your instructor

The tabs

Tab | What it does
Live Signals | Streams the four sensors live and records measurements
Spectrum | Shows the frequencies the structure vibrates at (natural frequencies and mode shapes)
Model Updating | Tunes a computer model of the structure to match your measurements
Sonification | Turns the vibrations into sound
Digital Twin Experiment | Runs the computer model alongside the real structure and compares them
Settings | Raspberry Pi connection, number of sensors, sensor positions and sampling rate

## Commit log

2026-04-09 Update main entry point and sensor config
2026-05-30 deep cuts and changes
    [Model1AccelerationImpulse.csv, Model1AccelerationSinStim.csv, Model1VelocityImpulse.csv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]
2026-06-30 Improve modal analysis accuracy, damping estimation, and Spectrum tab workflow
    1- Improve modal identification and add first-mode damping estimation:
    Updated FFT-based modal identification to use a direct Hann-windowed FFT instead of Welch PSD averaging. This gives better frequency resolution for short measurement windows and preserves phase information needed for signed mode shapes.
    Changed FFT mode-shape extraction from magnitude-only shapes to phase-aligned signed shapes using complex FFT values. This makes FFT-based mode shapes more consistent with FDD results and more useful for comparing structural mode directions.
    Added first-mode damping estimation from real sensor response data u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
2026-07-03 Added Spectrum-to-Model-Updating data transfer
    - Send calculated eigenfrequencies and mode shapes to Calibration manual input
    - Send calculated damping ratio to replace default damping value
2026-08-11 Add Bioacoustic Chorus sonification model under a split Sonification tab
    Turns the structure into a chorus of real recorded insect and amphibian voices.
    Each structural mode casts its own species: the mode's measured frequency maps
    logarithmically onto the audible carrier range and picks the nearest catalogued
    animal, then becomes that animal's chirp repetition rate 1:1 with no
    transposition - structural frequencies (1-15 Hz) already sit inside the range of
    insect chirp rates (5-30 Hz).
    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
2026-08-18 Add Digital Twin experiment and model-updating integration
    - Add Digital Twin Experiment tab with OpenSees numerical simulation
    - Add real-time comparison of physical and numerical structural responses
    - Add base excitation, time-history, FFT, and 3D response visualization
    - Add shaker-onset synchronization between physical and numerical models
    - Improve Digital Twin plotting, scaling, labels, and visualization
    - Add Continuous Update calibration handoff to Digital Twin
    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
2026-08-18 Save current project state
    [PSW_Button_Extender.stl, X306-pcb-v1.3(1).dxf, X306_OLED_ScrewTest_Sample.stl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]
2026-08-20 Fix 4-sensor mode shapes, sensor placement, and 100 Hz defaults
    Mode shapes (Spectrum + Model Updating tabs):
    - Add an 'unassigned' option to the sensor->story placement combos so a
    sensor not mounted on a model story (spare, or on the shake-table base)
    is excluded from the mode shapes instead of being forced onto a floor,
    where it was silently averaged in and biased that floor's value.
    - Fix presets writing only to the sensors they place: switching presets
    left unplaced sensors holding a stale story from the previous preset,
    quietly corrupting that floor's averaged value. Presets now explicitly
    unassign every sensor they do not place.
    - Stop piling extra sensors onto the top sto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
2026-09-07 4 sensor implementation check phase 4
    [Model1AccelerationImpulse.csv, Model1AccelerationSinStim.csv, Model1VelocityImpulse.csv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]
2026-09-08 4 sensor fuly integrated
2026-09-17 Fix digital twin shaker trigger, plot smoothness, add cyclic duration
    Shaker onset detection fired on a still structure. The test compared the
    instantaneous signal against 4 sigma of a quiet baseline, which assumes
    Gaussian background; this rig carries short bursts far above that (quiet
    sigma 0.009-0.021 m/s2, bursts to 1.4), so the first ambient knock after
    Start looked like the shaker. Replaced with a 0.5 s moving RMS that must
    hold for 0.25 s, thresholded off the quiet-window RMS and the excitation
    amplitude. Tuned against 170 recorded story traces: a still structure never
    exceeds 0.23 m/s2 moving RMS, real shaking never falls below 0.88.
    The comparison canvas redrew the entire figure ev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
2026-09-17 Replace the Spectrum torsion plot with a plan view in real degrees
    The old view plotted a dimensionless twist-to-sway ratio against floor
    number. It was honest but unreadable: the number carried no unit, the pair
    and gyro sources shared an axis despite being on different scales, and on a
    rig where one floor carries a differenceable pair it collapsed to a single
    point.
    It now draws the slabs themselves, at the plan proportions from the model,
    each rotated by the rotation measured on that floor. The rest position is
    dashed behind a 25% fill in the floor's own colour. A floor selector chooses
    one floor or all of them, and every floor of the structure is drawn whether
    or not it produced a readi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
2026-09-27 Rewrite README for ProTELC camp students; ignore hardware/
    Step-by-step first-time setup for the 4-sensor configuration: sparse
    clone, venv install, MissionControl Wi-Fi, and the verwalter/sensor4
    host settings. Pi preparation moved to an instructor section.
2026-10-01 Fix stream, threading and Model Updating bugs; ready the 4-sensor camp setup
    Bug fixes, each covered by a new test:
    - Calibrate: the comparison report crashed on the default Bayesian result
    (BayesianResult has no .x), discarding every calibration.
    - Live capture: the modal buffer was never cleared, so after Stop/Start the
    analysis tabs could use the previous run's data.
    - Stop froze the GUI for 5 s (queued thread.quit while the GUI thread waited).
    - Stopping the stream could crash or leave the ingest thread running: the
    parentless worker was destroyed from the GUI thread.
    - Closing during Continuous Update or a long Calibrate/Run Analysis destroyed
    a running QThread; Model Updating n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
2026-10-01 Add Structure Pulse: the measured building as a graphical score
    A second sonification model beside Bioacoustic Chorus. One recording is
    analysed once into a set of views; any view can then be played, with a
    playhead sweeping left to right while the curve's height drives a
    synthesiser, so the plot on screen and the sound are the same object.
    After Xenakis' UPIC (1977) -- x is time, y is frequency -- and Curtis
    Roads' pulsar synthesis as revived in Marcin Pietruszewski's nuPG. Pulsar
    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
2026-10-07 Stop blocking the GUI thread on worker threads; persist calibration
    Integrates the fixes a rig-test participant made on top of d1161c1, plus tests
    for each. Their dependency and README edits are deliberately not taken: removing
    the <3.13 cap would break Model Updating on Windows + Python 3.13/3.14, where
    pip is free to install openseespywin 3.8.0.0 (requires_python >=3.12) against
    python312.dll, and their deploy note contradicts both deploy scripts, which copy
    raspberrypi_scripts_4_sensor.
    The recurring defect was `thread.quit(); thread.wait(); thread.deleteLater()`
    run from a finished slot on the GUI thread with no timeout, which freezes the
    window until Windows reports "not responding". T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
2026-10-07 moved sonify button in model updating
